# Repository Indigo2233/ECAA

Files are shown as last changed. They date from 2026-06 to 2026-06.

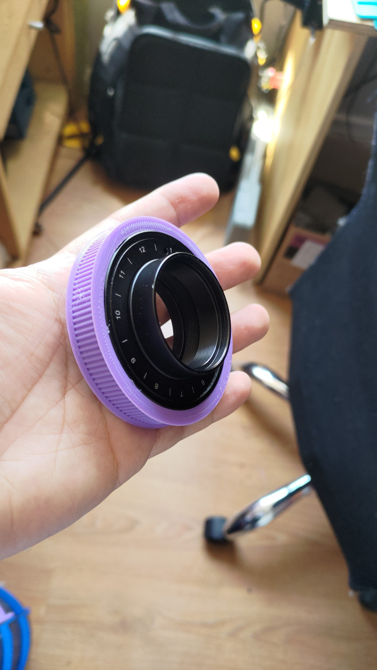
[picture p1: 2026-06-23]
m42/images/IMG-20220209-WA0020.jpeg

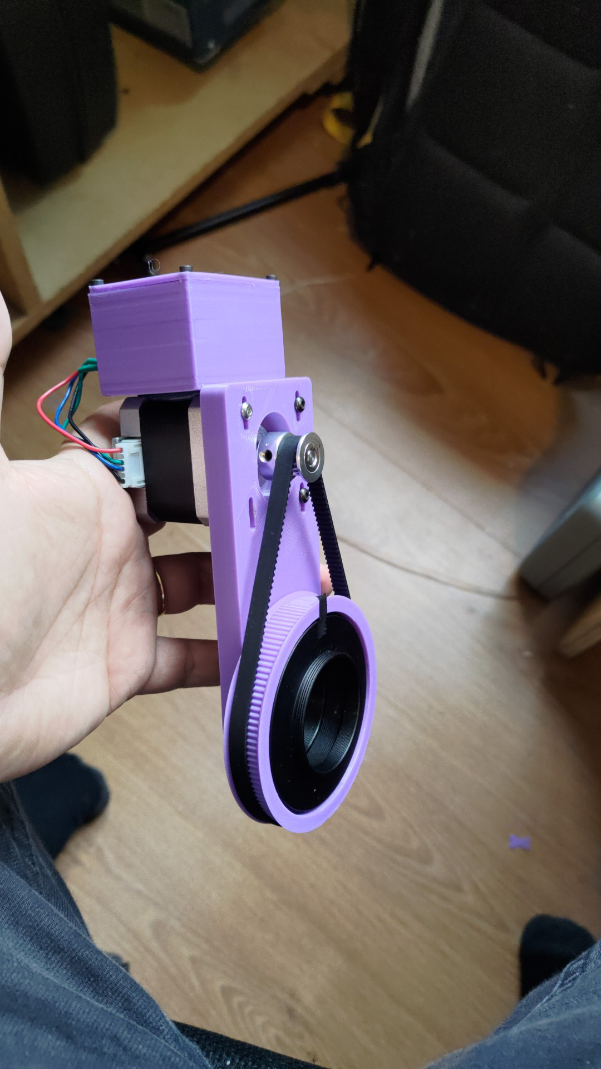
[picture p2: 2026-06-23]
m42/images/IMG-20220209-WA0058.jpeg

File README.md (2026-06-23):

# ECAA ESP8266 Rotator

ECAA is an ESP8266-based electric camera angle adjuster / field rotator project.
It includes firmware for the controller, an ASCOM rotator driver for PC
astronomy software, a simple ASCOM test client, and mechanical reference assets.

## Features

- ESP8266 firmware with AP+STA WiFi.
- Mobile control page served by the ESP8266 at `http://192.168.4.1`.
- ASCOM-compatible TCP text protocol on port `4030`.
- WebSocket status updates on port `81`.
- Legacy Arduino Nano firmware kept as a protocol reference.
- ASCOM .NET Framework driver with Serial and TCP transport options.
- Mechanical assets for M42 and M54 variants.

## Repository Layout

- `ESP8266RotatorFirmware/`
  - Main ESP8266 firmware, firmware-specific README, and a browser-only mock
    control page.
- `ArduinoRotatorFirmware_ver1008/`
  - Original Arduino Nano firmware.
- `driver/scopefocusRotatorDriver/`
  - ASCOM rotator driver source. The folder name is historical; the public
    ASCOM driver identity is `ASCOM.ECAA.Rotator`.
- `driver/RotatorTest/`
  - Simple Windows Forms ASCOM test client.
- `m42/` and `m54/`
  - STL, SolidWorks, and reference image assets.
- `AGENTS.md`
  - Detailed implementation notes for future development agents.

## Default WiFi

- AP SSID: `CAA-Rotator-<chipid>`
- AP password: `012345678`
- Mobile control page: `http://192.168.4.1`
- ASCOM TCP port: `4030`
- WebSocket port: `81`

## Hardware Summary

Default ESP8266 board target:

- Wemos D1 mini or NodeMCU

Default wiring:

- STEP: D1 / GPIO5
- DIR: D2 / GPIO4
- ENABLE: D5 / GPIO14, active low
- HALL: D6 / GPIO12, active low
- CW: D7 / GPIO13, active low
- CCW: D0 / GPIO16, active low with an external 10k pull-up to 3.3V

Soldering guide for the photographed NodeMCU-style board:

- Orient the board with the USB connector at the bottom and the ESP8266 antenna
  at the top. Use the printed pin labels on the board as the reference.
- The required signal pads are on the right-side header in the photo:
  `D0`, `D1`, `D2`, `D5`, `D6`, `D7`, `GND`, and `3V3`.
- Solder pin headers first if the rotator will be serviced later. Direct wire
  soldering is acceptable for a permanent build; add strain relief near the
  board edge.

| Board pad | Connect to | Notes |
| --- | --- | --- |
| `D1` / GPIO5 | Stepper driver `STEP`, `PUL`, or `CLK` | 3.3V logic pulse output. |
| `D2` / GPIO4 | Stepper driver `DIR` | Direction output. Reverse in firmware or web UI if rotation is inverted. |
| `D5` / GPIO14 | Stepper driver `ENABLE` or `ENA` | Active low. The firmware pulls it low when the driver should be enabled. |
| `D6` / GPIO12 | Hall sensor output | Active low. Sensor output must stay at 3.3V or lower. |
| `D7` / GPIO13 | CW manual button | Wire the other side of the button to `GND`. |
| `D0` / GPIO16 | CCW manual button | Wire the other side of the button to `GND`; add a 10k pull-up from `D0` to `3V3`. |
| `3V3` | Hall sensor VCC, or driver logic VDD when supported | Use only for low-current 3.3V logic or sensors. |
| `GND` | Stepper driver logic GND, Hall GND, button common, and 12V supply negative | Common ground is required for STEP/DIR/ENABLE to be valid. |
| USB or `Vin` | ESP8266 board power | Prefer USB during testing. If using a buck converter, feed regulated 5V to `Vin` and `GND`. |

External stepper driver wiring:

| Driver terminal | Connect to | Notes |
| --- | --- | --- |
| `VMOT`, `12V+`, or motor supply `+` | External 12V positive | Set the driver current limit before load testing. |
| Motor supply `GND` | External 12V negative and ESP8266 `GND` | This is the shared power return. |
| `A+`, `A-`, `B+`, `B-` | Stepper motor coils | Swap one coil pair if the physical direction is unsuitable. |
| `VDD` or `VIO` | `3V3` only when the driver supports 3.3V logic | Use a level shifter or compatible driver for 5V-only logic inputs. |
| Microstep pins | Fixed high/low jumpers as required | Update `stepsPerDegree` after changing microstepping. |

Power requirements:

- Use an external 12V supply for the stepper driver motor power.
- Connect ESP8266 GND, stepper driver logic GND, and the 12V supply negative
  terminal together.
- Keep 12V away from ESP8266 `5V`, `3.3V`, and GPIO pins.
- ESP8266 GPIO uses 3.3V logic. Use level shifting or a 3.3V-compatible stepper
  driver when required.

Initial electrical check:

1. Power only the ESP8266 over USB and confirm the AP appears.
2. Wire `GND`, `STEP`, `DIR`, and `ENABLE` to the stepper driver with motor
   power disconnected.
3. Verify `ENABLE` changes state and `STEP` pulses during a small move command.
4. Connect the Hall sensor and confirm `Home` reacts when the sensor is
   triggered.
5. Connect the external 12V supply and motor after the driver current limit is
   set.

Home and zero behavior:

- The Hall sensor is only the mechanical reference point.
- `Set 0` stores the current physical position as the user-defined zero angle.
- The saved zero offset is persistent.
- `Home` finds the Hall sensor first, then automatically returns to the saved
  user-defined `0 deg` position.

## Firmware Build

Expected Arduino environment:

- Arduino ESP8266 core
- Board: Wemos D1 mini or NodeMCU
- Libraries: `AccelStepper`, `WebSocketsServer`

Open and upload:

```text
ESP8266RotatorFirmware/ESP8266RotatorFirmware.ino
```

Preview the mobile control page locally:

```text
ESP8266RotatorFirmware/mock-control-page.html
```

After upload:

1. Power the ESP8266.
2. Connect a phone to `CAA-Rotator-<chipid>` using password `012345678`.
3. Open `http://192.168.4.1`.
4. Verify status updates, halt, home, and small relative moves before attaching
   motor load.

## ASCOM Driver

Public identity:

- ProgID: `ASCOM.ECAA.Rotator`
- Chooser name: `ECAA ESP8266 Rotator`
- DLL name: `ASCOM.ECAA.Rotator.dll`

Build requirements:

- Visual Studio or MSBuild
- .NET Framework 4.8 Developer Pack
- ASCOM Platform developer components

Build command from repository root:

```powershell
& "C:\Program Files\Microsoft Visual Studio\2022\Community\MSBuild\Current\Bin\MSBuild.exe" driver\scopefocusRotatorDriver\scopefocusRotatorDriver.csproj /p:Configuration=Release /p:RegisterForComInterop=false /m
```

Driver setup defaults for ESP8266 TCP:

- Transport: `TCP`
- Host: `192.168.4.1`
- Port: `4030`
- Timeout: `3000`
- Steps/degree: `100`

## Legacy Text Protocol

Commands are ASCII text terminated by `#`.

- `G#`: returns `P <steps>;M <true|false>#`
- `M <steps>#`: move to absolute step position
- `P <steps>#`: set current logical step position and update the saved zero offset
- `H#`: start homing
- `S#`: stop movement
- `R <0|1>#`: set direction inversion
- `C <0|1>#`: set continuous hold
- `V#`: firmware version
- `I#`: JSON status
- `D <stepsPerDegree>#`: set steps per degree and recompute two-turn range

## Validation Checklist

- ESP8266 AP starts with the expected SSID and password.
- `http://192.168.4.1` loads the control page from a phone.
- `GET /api/status` returns JSON.
- TCP command `G#` on port `4030` returns a `#`-terminated response.
- ASCOM setup dialog shows `Serial` and `TCP` transport options.
- ASCOM test client can connect, read position, move, halt, and home.

## Development Notes

- Build outputs, Visual Studio caches, generated installers, DLLs, PDBs, and
  Arduino build artifacts are ignored by `.gitignore`.
- Keep `AGENTS.md` updated when driver identity, protocol, wiring, or build
  assumptions change.

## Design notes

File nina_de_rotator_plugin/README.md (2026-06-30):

# Alt-Az De-Rotator Plugin for N.I.N.A.

Actively compensates for field rotation on Alt-Azimuth telescope mounts by
calculating the required rotation rate and commanding an ASCOM Rotator (e.g. ECAA).

Forked from [ArchitectJuan/Nina_Rotator_Plugin](https://github.com/ArchitectJuan/Nina_Rotator_Plugin)
with fixes for the ECAA/ASCOM ecosystem:

- **Accumulated error tracking**: slow field rotation rates (< 36°/hr) are
  accumulated across polling cycles and applied in one move when the deadband
  (0.01°) is reached, preventing stalls.
- **Direct MoveAbsolute**: bypasses the NINA mediator's `Move()` method which
  does not reliably call the ASCOM driver in NINA 3.x.
- **Diagnostic logging**: logs each derotation move with the applied angle
  and current field-rotation rate.

## Build

Requires .NET 8.0 SDK + local NINA installation.

```powershell
dotnet build AltAzDeRotator.csproj -c Release
```

## Install

1. Copy contents of `Builds\AltAz.DeRotator\` into
   `%localappdata%\NINA\Plugins\3.0.0\AltAz.DeRotator\`
2. Restart NINA.
3. Connect both Telescope (Alt-Az) and Rotator (e.g. ECAA) in Equipment tab.
4. Open **Alt-Az De-Rotator** dockable window, toggle **Enable De-Rotation** ON.

## License

MIT
- **Micro-step Prevention:** Intelligent 0.01-degree thresholding ensures your Rotator is only commanded when necessary, preventing unnecessary hardware wear.
- **N.I.N.A. 3.x Compatibility:** Built against the modern .NET 8.0 framework and N.I.N.A. 3.0 Managed Extensibility Framework (MEF).

## Version History
- **V1.1.0:** Added User Interface and On/Off switch control. Migrated to DockableVM pattern.
- **V1.0.0:** Initial Release. Features background polling service, dynamic rate calculation, and MEF dependency injection.

## Installation
Refer to the `UserGuide.md` for complete installation and usage instructions.

## Building from Source
This project requires Visual Studio or the .NET 8.0 SDK.
Run `dotnet build AltAzDeRotator.csproj` to compile the library. Output files are automatically copied to the `Builds\Nina_Rotator_Plugin_V1.0` folder.





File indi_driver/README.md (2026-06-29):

# INDI Driver for CAA Rotator

INDI driver for the CAA (Camera Angle Adjuster) — supports ESP8266 and Arduino
Nano hardware, over TCP or Serial.

Firmware repo: <https://github.com/Indigo2233/ECAA>

## Hardware Support

| Hardware | Transport | Default |
|---|---|---|
| ESP8266 | TCP (WiFi) | `192.168.4.1:4030` |
| ESP8266 | Serial (USB) | `/dev/ttyUSB0` @ 9600 |
| Arduino Nano | Serial (USB) | `/dev/ttyUSB0` @ 9600 |

All three use the same text protocol — switch transport in the INDI control
panel, no need to restart the driver.

## Build & Install

```bash
mkdir build && cd build
cmake .. -DCMAKE_INSTALL_PREFIX=/usr
make -j$(nproc)
sudo make install
```

## Run

```bash
# Standalone (waits for INDI client):
indi_caa_rotator

# With debug output:
INDI_DEBUG=1 indi_caa_rotator
```

In Ekos / KStars: Profile Editor → Rotator → **CAA Rotator**.

## INDI Properties

| Group | Property | Description |
|---|---|---|
| Transport | `TRANSPORT` | Switch between TCP / Serial |
| TCP Config | `TCP_HOST`, `TCP_PORT` | ESP8266 WiFi address |
| Serial Config | `SERIAL_PORT`, `SERIAL_BAUD` | Serial port and baud rate |
| Settings | `STEPS_PER_DEGREE` | Motor steps per degree (e.g. 635) |
| Settings | `CMD_TIMEOUT` | Command timeout in ms |
| Main | `GOTO` | Move to absolute sky angle |
| Main | `SYNC` | Align current position to sky angle |
| Main | `HOME` | Seek Hall sensor and return to zero |
| Main | `ABORT` | Halt movement |
| Info | `FW_VERSION` | Firmware version (read-only) |

## Protocol

Text commands terminated with `#`:

| Cmd | Description |
|-----|---|
| `G#` | Status: `P <steps>;M <moving>#` |
| `M <n>#` | Move to logical step position |
| `P <n>#` | Set current logical position (sync) |
| `H#` | Start homing |
| `S#` | Stop |
| `V#` | Firmware version |
| `D <n>#` | Set steps per degree (firmware int only) |

## Notes

- The driver sends `D <int>#` on connect to sync firmware steps-per-degree.
  The value is truncated to integer for firmware compatibility; full double
  precision is used for driver-side angle conversion.
- Serial transport uses POSIX termios (Linux/macOS) or Win32 CreateFile (Windows).
  Both serial and TCP work on all platforms.
- Homing is asynchronous; the driver polls `G#` until firmware reports idle.

## License

LGPL-2.1+ (same as libindi)

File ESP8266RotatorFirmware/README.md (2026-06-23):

# ESP8266RotatorFirmware

Arduino sketch for the ESP8266 CAA rotator controller.

`mock-control-page.html` is a browser-only preview of the control page. It uses
mock state and does not require an ESP8266.

## Board and libraries

- Board: Wemos D1 mini or NodeMCU
- Arduino ESP8266 core
- Libraries: `AccelStepper`, `WebSocketsServer`

## Default network

- AP SSID: `CAA-Rotator-<chipid>`
- AP password: `012345678`
- Control page: `http://192.168.4.1`
- ASCOM TCP protocol port: `4030`
- WebSocket status port: `81`

## Default wiring

- STEP: D1 / GPIO5
- DIR: D2 / GPIO4
- ENABLE: D5 / GPIO14, active low
- HALL: D6 / GPIO12, active low
- CW: D7 / GPIO13, active low
- CCW: D0 / GPIO16, active low with an external 10k pull-up to 3.3V

## Soldering guide

For the NodeMCU-style board shown in the project discussion, orient the board
with USB at the bottom and the ESP8266 antenna at the top. Follow the silkscreen
pin labels on the board.

| Board pad | Connect to | Notes |
| --- | --- | --- |
| `D1` / GPIO5 | Stepper driver `STEP`, `PUL`, or `CLK` | 3.3V logic pulse output. |
| `D2` / GPIO4 | Stepper driver `DIR` | Direction output. Toggle Reverse in the web UI if needed. |
| `D5` / GPIO14 | Stepper driver `ENABLE` or `ENA` | Active low. |
| `D6` / GPIO12 | Hall sensor output | Active low. Keep the output at 3.3V or lower. |
| `D7` / GPIO13 | CW manual button | Button shorts to `GND` when pressed. |
| `D0` / GPIO16 | CCW manual button | Button shorts to `GND`; add 10k from `D0` to `3V3`. |
| `3V3` | Hall VCC, or driver logic VDD when supported | Low-current 3.3V logic only. |
| `GND` | Driver logic GND, Hall GND, button common, and 12V negative | All logic signals require common ground. |
| USB or `Vin` | ESP8266 power | Use USB for testing, or regulated 5V to `Vin` and `GND`. |

External driver power:

- 12V positive goes to the stepper driver motor supply positive terminal.
- 12V negative goes to the stepper driver motor supply GND and ESP8266 `GND`.
- Stepper motor coils connect only to the driver motor outputs.
- Driver logic `VDD` / `VIO` may use ESP8266 `3V3` only when that driver accepts
  3.3V logic.
- Set the driver current limit before connecting the motor load.

Use an external 12V supply for the stepper driver motor power. Connect ESP8266
GND, stepper driver logic GND, and the 12V supply negative terminal together.
The ESP8266 GPIO pins are 3.3V logic. Do not connect 12V to the ESP8266 5V,
3.3V, or GPIO pins.

## Home and zero position

- The Hall sensor is used only as the mechanical reference point.
- `Set 0` stores the current physical position as the user-defined zero angle.
- The user-defined zero angle is saved in EEPROM as a step offset from the Hall
  reference.
- `Home` first finds the Hall sensor, resets the mechanical reference, then
  automatically moves to the saved user-defined `0 deg` position.

## Legacy protocol

Commands are ASCII text terminated by `#`.

- `G#`: returns `P <steps>;M <true|false>#`
- `M <steps>#`: move to an absolute step position
- `P <steps>#`: set the current logical step position and update the saved zero offset
- `H#`: start homing
- `S#`: stop movement
- `R <0|1>#`: set direction inversion
- `C <0|1>#`: set continuous hold
- `V#`: firmware version
- `I#`: JSON status
- `D <stepsPerDegree>#`: set steps per degree and recompute the two-turn range

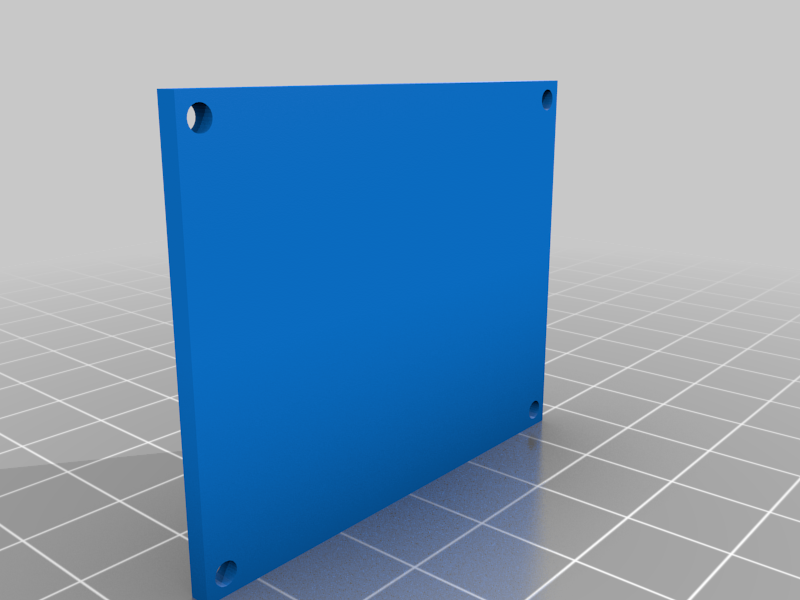
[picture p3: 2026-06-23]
m42/images/tapa_caja_rotador.png

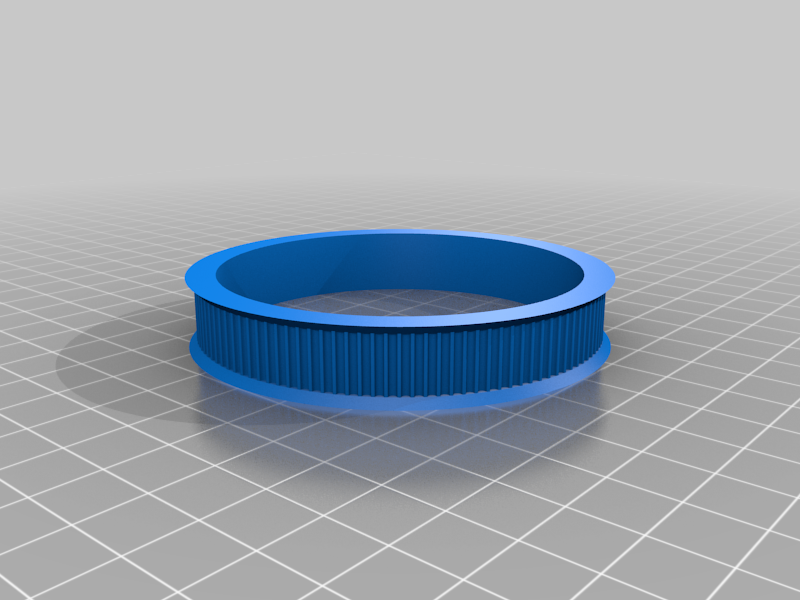
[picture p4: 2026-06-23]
m42/images/pulley_rotator.png

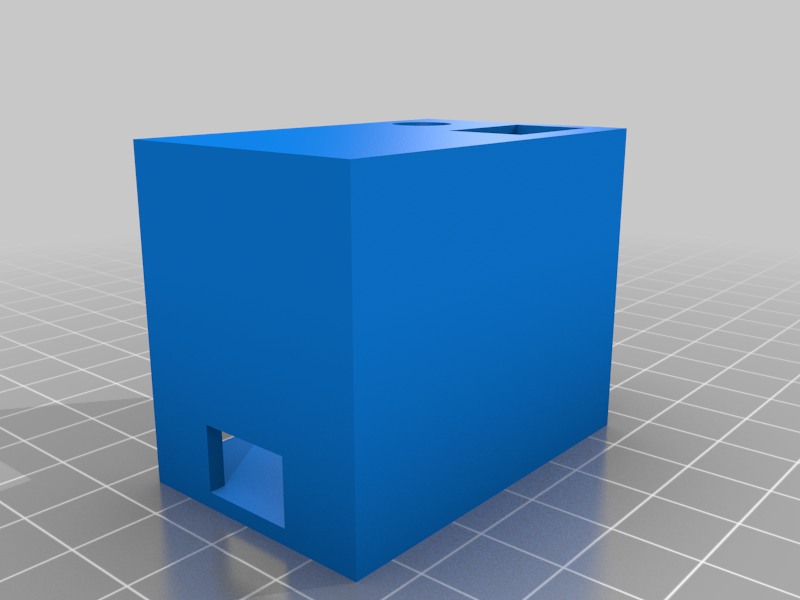
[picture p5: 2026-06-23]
m42/images/caja_rotador.png

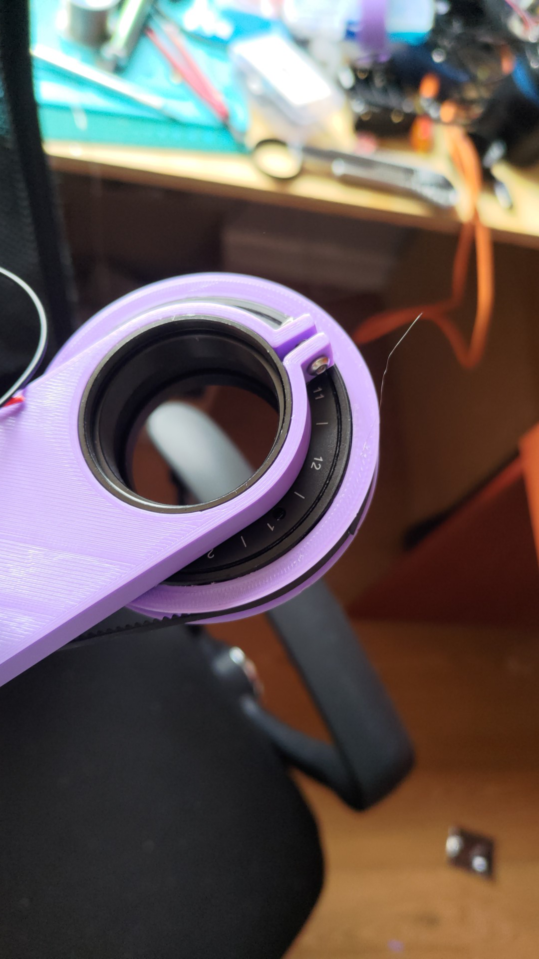
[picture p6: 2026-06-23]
m42/images/IMG-20220209-WA0037.jpeg

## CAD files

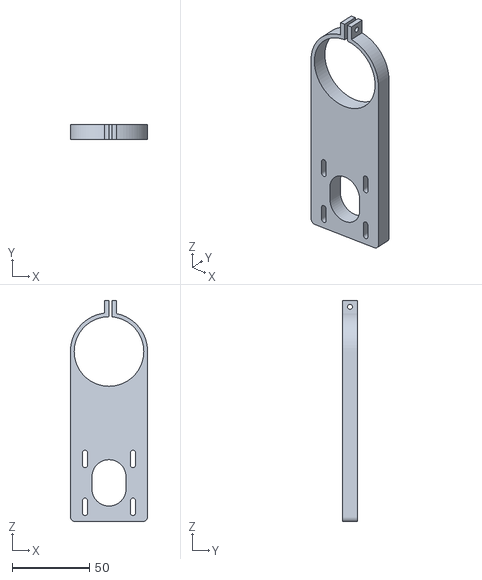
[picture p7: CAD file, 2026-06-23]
m42/rotador_astroquinta_v1.stl
50.0 x 10.0 x 143.0

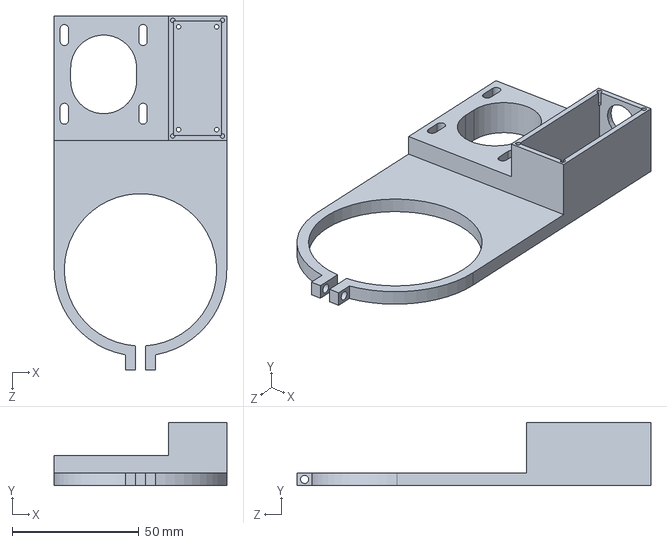
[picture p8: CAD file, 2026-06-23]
m54/m54_v2.1_B.SLDPRT
68.0 x 25.0 x 139.5 mm

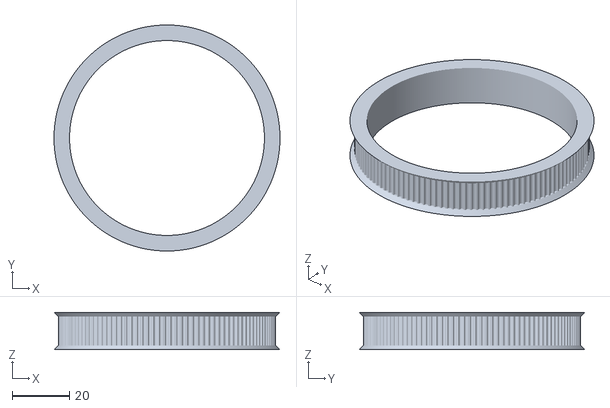
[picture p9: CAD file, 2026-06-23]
m42/pulley_rotator.stl
78.9 x 78.9 x 13.0

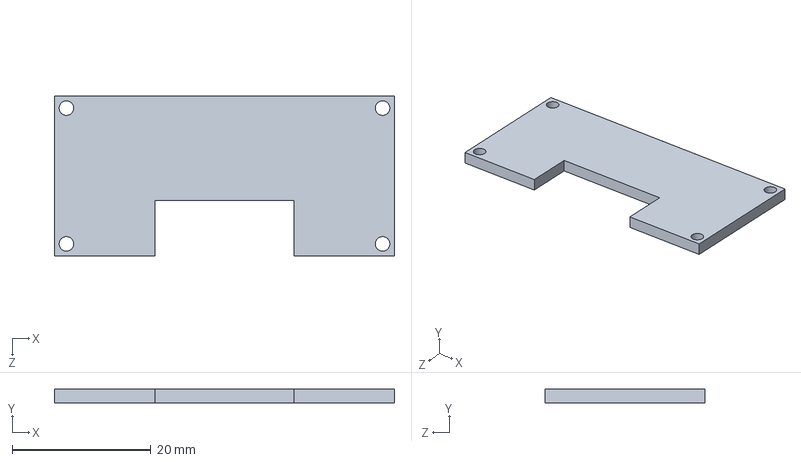
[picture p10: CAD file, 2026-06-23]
m54/m54 cover.SLDPRT
49.0 x 2.00 x 23.0 mm

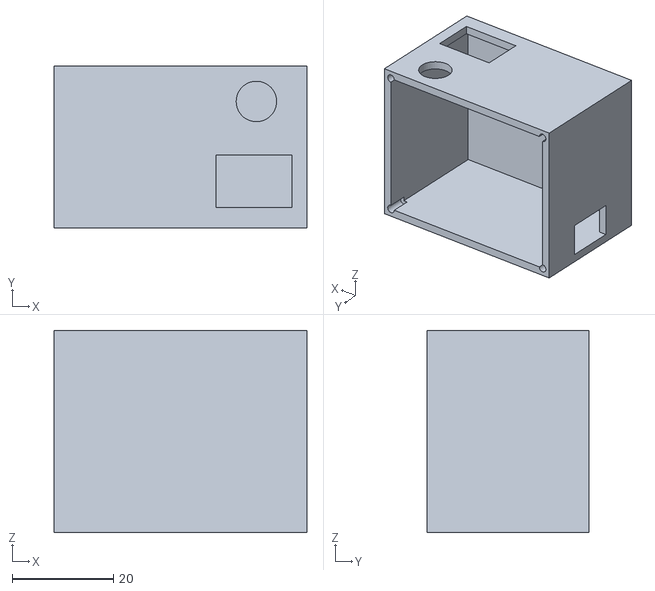
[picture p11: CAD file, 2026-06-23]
m42/caja_rotador.stl
50.0 x 32.0 x 40.0

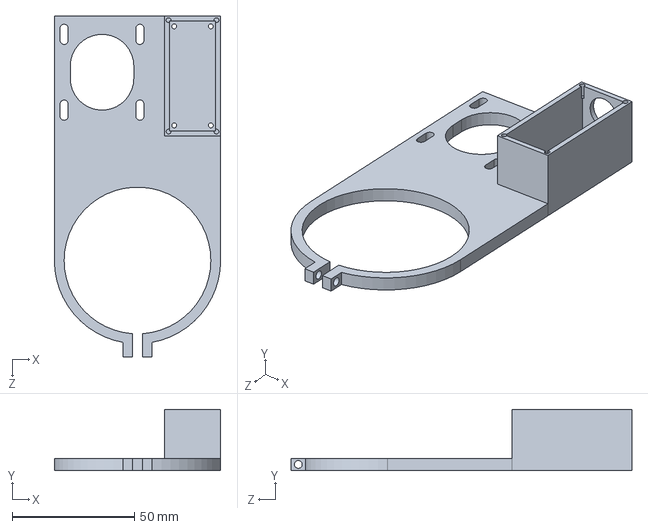
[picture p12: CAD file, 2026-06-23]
m54/m54_v2.SLDPRT
68.0 x 25.0 x 139.5 mm

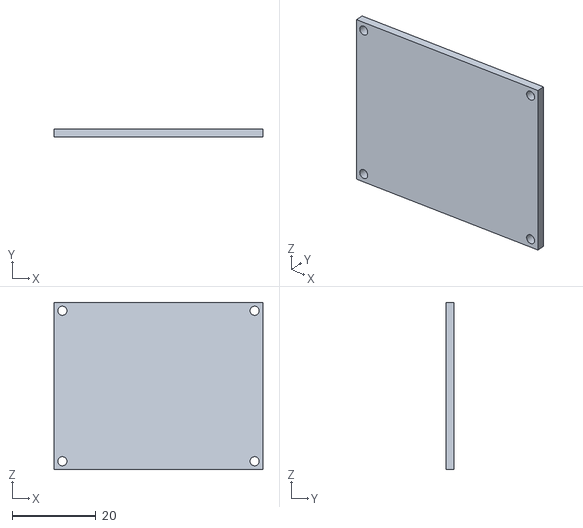
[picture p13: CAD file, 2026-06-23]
m42/tapa_caja_rotador.stl
50.0 x 2.00 x 40.0

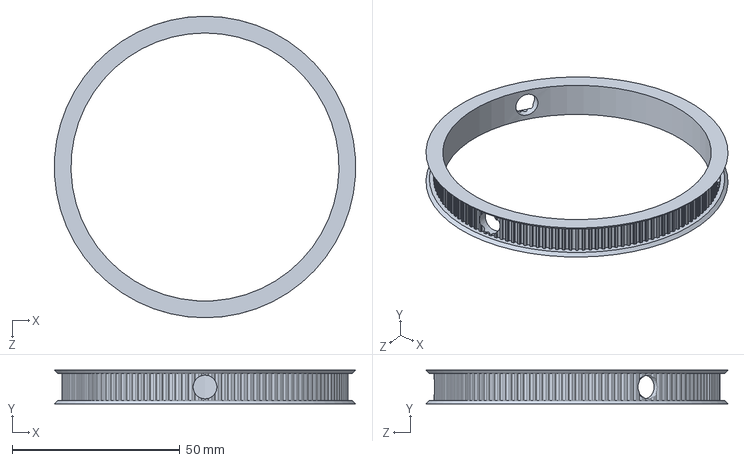
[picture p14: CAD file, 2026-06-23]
m54/m54 gear.SLDPRT
89.8 x 10.0 x 90.0 mm

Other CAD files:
m54/m54 cover.STL
m54/m54 gear.STL
m54/m54_v2.1_B.STL
m54/m54_v2.STL

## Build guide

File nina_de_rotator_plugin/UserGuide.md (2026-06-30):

# Alt-Az De-Rotator User Guide

Welcome to the Alt-Az De-Rotator Plugin for N.I.N.A. This guide will walk you through the installation and operational steps to get your field rotator compensating for Alt-Azimuth tracking.

## 1. Installation

1. Navigate to the `Builds\AltAz.DeRotator` directory in this repository.
2. Ensure you have the following files:
   - `AltAzDeRotator.dll`
   - `manifest.json`
3. Locate your N.I.N.A. 3.0 Plugins version folder. By default, this is located at:
   `%localappdata%\NINA\Plugins\3.0.0`
4. Create a new folder inside the `3.0.0` directory named exactly **`AltAz.DeRotator`**.
5. Copy the contents of `Builds\AltAz.DeRotator` into this new folder.
6. **Important**: The folder name must match the plugin ID `AltAz.DeRotator`.
7. Restart N.I.N.A.

## 2. Requirements

- N.I.N.A. version 3.0 or higher.
- A connected and communicating Telescope mount (ASCOM, EQMOD, GreenSwamp, etc.) with valid Altitude and Azimuth telemetry.
- A connected Rotator (ASCOM-compatible) capable of Absolute Positioning movements.

## 3. Operation

Once initialized, the plugin provides a dedicated UI for monitoring and control.

1. **Open the Status Window:** In N.I.N.A., go to the **Plugins** tab or check the **Windows** menu for "Alt-Az De-Rotator". This dockable window shows real-time Altitude, Azimuth, and calculated Rotation Rate.
2. **Connect your Equipment:** Ensure both your Telescope and your Rotator are connected in the **Equipment** tab.
3. **Enable/Disable:** Use the **Enable De-Rotation** checkbox in the plugin window to start or stop active compensation. 
4. **Automatic Adjustments:** Every second, if enabled, the plugin calculates the required position offset. If the required change exceeds `0.01 degrees`, a command is issued to the Rotator. 

*Note: You can dock the status window anywhere in your N.I.N.A. layout to keep an eye on rotation during your session!*

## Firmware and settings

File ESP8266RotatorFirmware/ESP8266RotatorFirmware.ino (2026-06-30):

#include <AccelStepper.h>
#include <EEPROM.h>
#include <ESP8266WebServer.h>
#include <ESP8266WiFi.h>
#include <ESP8266mDNS.h>
#include <WebSocketsServer.h>
#include <ctype.h>
#include <math.h>

#define STEP_PIN D1
#define DIR_PIN D2
#define ENABLE_PIN D5
#define HALL_PIN D6
#define CW_PIN D7
#define CCW_PIN D3

#define DEVICE_RESPONSE "CAA ESP8266 Rotator ver 2001"
#define FIRMWARE_VERSION 2001
#define EEPROM_SIZE 512
#define SETTINGS_MAGIC 0xCAAF8266UL
#define ASCOM_TCP_PORT 4030
#define WEBSOCKET_PORT 81
#define MAX_TCP_CLIENTS 4

const char *AP_PASSWORD = "012345678";
IPAddress apIp(192, 168, 4, 1);
IPAddress apGateway(192, 168, 4, 1);
IPAddress apSubnet(255, 255, 255, 0);

struct RotatorSettings {
  uint32_t magic;
  long position;
  int stepsPerDegree;
  long maxSteps;
  int maxSpeed;
  int acceleration;
  int manualMoveStepSize;
  int findHomeStepSize;
  bool hold;
  bool reversed;
  char staSsid[32];
  char staPassword[64];
  long homeOffsetSteps;
  char tcpPassword[16];
  char apPassword[32];
  char nickname[32];
  int backlashSteps;
};

RotatorSettings settings;
AccelStepper stepper(AccelStepper::DRIVER, STEP_PIN, DIR_PIN);
ESP8266WebServer server(80);
WebSocketsServer webSocket(WEBSOCKET_PORT);
WiFiServer tcpServer(ASCOM_TCP_PORT);
WiFiClient tcpClients[MAX_TCP_CLIENTS];

String tcpBuffers[MAX_TCP_CLIENTS];
bool tcpAuthenticated[MAX_TCP_CLIENTS];
String serialBuffer;
String apSsid;
String mdnsHostname;

bool positionSaved = true;
bool findingHome = false;
bool homeFound = false;
bool backlashCompensating = false;
long backlashFinalTarget = 0;
bool manualMoveCW = false;
bool manualMoveCCW = false;
int lastCWState = HIGH;
int lastCCWState = HIGH;
unsigned long lastCWDebounce = 0;
unsigned long lastCCWDebounce = 0;
unsigned long lastStatusBroadcast = 0;
const unsigned long debounceDelayMs = 20;

const char INDEX_HTML[] PROGMEM = R"rawliteral(
<!doctype html>
<html lang="en">
<head>
<meta charset="utf-8">
<meta name="viewport" content="width=device-width,initial-scale=1,viewport-fit=cover">
<title>CAA Rotator</title>
<style>
:root{color-scheme:dark;--bg:#111318;--panel:#1a1f28;--panel2:#202734;--line:#384252;--text:#f2f5f8;--muted:#aeb8c6;--accent:#4db6ac;--warn:#f4b24e;--danger:#ee6b63;--ok:#7bc96f}
*{box-sizing:border-box}
body{margin:0;background:var(--bg);color:var(--text);font-family:system-ui,-apple-system,Segoe UI,Roboto,Arial,sans-serif;letter-spacing:0}
main{max-width:720px;margin:0 auto;padding:18px 14px 28px}
header{display:flex;align-items:center;justify-content:space-between;gap:12px;margin-bottom:14px}
h1{font-size:22px;margin:0;font-weight:680}
.status{font-size:13px;color:var(--muted)}
.grid{display:grid;grid-template-columns:1fr;gap:10px}
section{border:1px solid var(--line);background:var(--panel);border-radius:8px;padding:12px}
.readout{display:grid;grid-template-columns:1fr 1fr;gap:10px}
.metric{background:var(--panel2);border:1px solid var(--line);border-radius:8px;padding:10px;min-height:76px}
.metric span{display:block;color:var(--muted);font-size:12px;margin-bottom:8px}
.metric strong{font-size:22px;line-height:1.2;white-space:nowrap}
.row{display:flex;gap:8px;align-items:center;flex-wrap:wrap}
.controls{display:grid;grid-template-columns:repeat(3,1fr);gap:8px}
button,input,select{font:inherit}
button{border:1px solid var(--line);background:#263244;color:var(--text);border-radius:8px;min-height:44px;padding:0 12px;cursor:pointer}
button:active{transform:translateY(1px)}
button.primary{background:var(--accent);border-color:var(--accent);color:#071211;font-weight:700}
button.warn{background:var(--warn);border-color:var(--warn);color:#211400;font-weight:700}
button.danger{background:var(--danger);border-color:var(--danger);color:#210706;font-weight:700}
button.toggle.active{background:var(--ok);border-color:var(--ok);color:#061008;font-weight:700}
label{display:grid;gap:5px;color:var(--muted);font-size:12px;min-width:0}
input{width:100%;background:#121720;color:var(--text);border:1px solid var(--line);border-radius:8px;min-height:42px;padding:8px 10px}
.form{display:grid;grid-template-columns:1fr 1fr;gap:10px}
.wide{grid-column:1/-1}
.dial{aspect-ratio:1;max-width:330px;margin:6px auto 12px;border:2px solid var(--line);border-radius:50%;position:relative;background:radial-gradient(circle,#202734 0,#151a22 68%,#111318 100%)}
.needle{position:absolute;left:50%;top:50%;width:3px;height:43%;background:var(--accent);transform-origin:50% 0;transform:rotate(0deg);border-radius:3px}
.hub{position:absolute;left:50%;top:50%;width:18px;height:18px;background:var(--accent);border-radius:50%;transform:translate(-50%,-50%)}
.tick{position:absolute;color:var(--muted);font-size:12px}
.t0{left:50%;top:8px;transform:translateX(-50%)}.t90{right:8px;top:50%;transform:translateY(-50%)}.t180{left:50%;bottom:8px;transform:translateX(-50%)}.t270{left:8px;top:50%;transform:translateY(-50%)}
.small{font-size:12px;color:var(--muted)}
.toast{font-size:13px;color:var(--ok);min-height:20px;transition:color .3s;display:flex;align-items:center;gap:6px}
.toast.info{color:var(--accent)}
.toast.warn{color:var(--warn)}
.spinner{display:inline-block;width:14px;height:14px;border:2px solid var(--line);border-top-color:var(--accent);border-radius:50%;animation:spin .7s linear infinite;flex-shrink:0}
@keyframes spin{to{transform:rotate(360deg)}}
@media (min-width:680px){.grid{grid-template-columns:1fr 1fr}.span{grid-column:1/-1}}
</style>
</head>
<body>
<main>
<header>
<h1 id="pageTitle">CAA Rotator</h1>
<div class="status" id="link">Connecting</div>
</header>
<div class="grid">
<section class="span">
<div class="dial" id="dial">
<div class="tick t0">0</div><div class="tick t90">90</div><div class="tick t180">180</div><div class="tick t270">270</div>
<div class="needle" id="needle"></div><div class="hub"></div>
</div>
<div class="readout">
<div class="metric"><span>Angle</span><strong id="angle">--</strong></div>
<div class="metric"><span>Steps</span><strong id="steps">--</strong></div>
</div>
</section>
<section>
<div class="form">
<label class="wide">Absolute angle<input id="absoluteAngle" type="number" min="0" max="359.99" step="0.01" value="0"></label>
<button class="primary wide" id="moveAbsolute">Move</button>
<button data-rel="-10">-10</button><button data-rel="-1">-1</button><button data-rel="-0.1">-0.1</button>
<button data-rel="0.1">+0.1</button><button data-rel="1">+1</button><button data-rel="10">+10</button>
<button class="danger" id="halt">STOP</button><button id="home">Home</button><button id="setZero">Set 0</button>
</div>
</section>
<section>
<div class="form">
<button class="toggle" id="hold">Hold</button>
<button class="toggle" id="reverse">Reverse</button>
<label>Steps/degree<input id="stepsPerDegree" type="number" min="1" step="1"></label>
<label>Max speed<input id="maxSpeed" type="number" min="1" step="1"></label>
<label>Acceleration<input id="acceleration" type="number" min="1" step="1"></label>
<label>Manual step<input id="manualStep" type="number" min="1" step="1"></label>
<label>Device Name<input id="nickname" type="text" maxlength="31" placeholder="mDNS hostname"></label>
<label>AP Password<input id="apPassword" type="password" maxlength="31" placeholder="default: 012345678"></label>
<label>STA SSID<input id="staSsid" type="text" maxlength="31"></label>
<label>STA Password<input id="staPassword" type="password" maxlength="63"></label>
<label>TCP Password<input id="tcpPassword" type="password" maxlength="15" placeholder="empty = no auth"></label>
<button class="primary wide" id="saveSettings">Save settings</button>
<div class="toast wide" id="saveMsg"></div>
<div class="small wide" id="network"></div>
</div>
</section>
</div>
</main>
<script>
const $=id=>document.getElementById(id);
let state={};
async function api(path,body){
 const opt=body===undefined?{}:{method:'POST',headers:{'Content-Type':'application/json'},body:JSON.stringify(body)};
 const res=await fetch(path,opt);
 if(!res.ok)throw new Error(path);
 return res.json();
}
function setState(s){
 state=s;
 const title=s.nickname?s.nickname:'CAA Rotator';
 document.title=title;
 $('pageTitle').textContent=title;
 $('angle').textContent=(s.angle??0).toFixed(2)+'°';
 $('steps').textContent=String(s.positionSteps??0);
 $('needle').style.transform='rotate('+((s.angle??0)+180)+'deg)';
 $('link').textContent=s.isMoving?'Moving':'Ready';
 $('hold').classList.toggle('active',!!s.hold);
 $('reverse').classList.toggle('active',!!s.reversed);
 $('stepsPerDegree').value=s.stepsPerDegree??100;
 $('maxSpeed').max=(s.stepsPerDegree??100)*10;
 $('maxSpeed').value=s.maxSpeed??800;
 $('acceleration').value=s.acceleration??1000;
 $('manualStep').value=s.manualStep??50;
 if(document.activeElement!==$('nickname'))$('nickname').value=s.nickname||'';
 if(document.activeElement!==$('staSsid'))$('staSsid').value=s.staSsid||'';
 if(document.activeElement!==$('tcpPassword'))$('tcpPassword').placeholder=s.tcpLocked?'••••••••':'empty = no auth';
 if(document.activeElement!==$('apPassword'))$('apPassword').placeholder=s.apCustom?'••••••••':'default: 012345678';
 const staIp=s.staIp&&s.staIp!=='0.0.0.0'?s.staIp:'not connected';
 const mdnsHost=(s.mdns||'').replace('.local','');
 $('network').innerHTML='AP: '+(s.apIp||'192.168.4.1')+' | STA: '+staIp+'<br>mDNS: <b>'+(s.mdns||'')+'</b> | TCP: '+(s.tcpPort||4030)+'<br>ASCOM Host: <b>'+mdnsHost+'</b> or <b>'+staIp+'</b>';
}
async function refresh(){try{setState(await api('/api/status'));}catch(e){$('link').textContent='Disconnected';}}
function connectWs(){
 const ws=new WebSocket('ws://'+location.hostname+':81/');
 ws.onopen=()=>{$('link').textContent='Connected'};
 ws.onmessage=e=>{try{setState(JSON.parse(e.data));}catch(_){}};
 ws.onclose=()=>{setTimeout(connectWs,1200);};
}
$('moveAbsolute').onclick=()=>api('/api/move',{angle:Number($('absoluteAngle').value)}).then(setState);
document.querySelectorAll('[data-rel]').forEach(b=>b.onclick=()=>api('/api/move',{relativeDeg:Number(b.dataset.rel)}).then(setState));
$('halt').onclick=()=>api('/api/halt',{}).then(setState);
$('home').onclick=()=>api('/api/home',{}).then(setState);
$('setZero').onclick=()=>api('/api/set-position',{angle:0}).then(setState);
$('hold').onclick=()=>api('/api/settings',{hold:!state.hold}).then(setState);
$('reverse').onclick=()=>api('/api/settings',{reversed:!state.reversed}).then(setState);
let staWaiting=false,staWatchTimer=null,staWatchCount=0;
function showMsg(text,cls,spin){
 const m=$('saveMsg');
 m.innerHTML=(spin?'<span class="spinner"></span>':'')+text;
 m.className='toast wide'+(cls?' '+cls:'');
}
async function watchStaIp(){
 if(!staWaiting)return;
 staWatchCount++;
 try{
  const s=await api('/api/status');
  if(s.staIp&&s.staIp!=='0.0.0.0'){
   staWaiting=false;
   showMsg('WiFi connected: '+s.staIp);
   if(staWatchTimer){clearInterval(staWatchTimer);staWatchTimer=null;}
   setState(s);
   return;
  }
  if(staWatchCount>30){staWaiting=false;showMsg('WiFi timeout - check SSID/password','warn');if(staWatchTimer){clearInterval(staWatchTimer);staWatchTimer=null;}}
 }catch(e){}
}
$('saveSettings').onclick=async()=>{
 const btn=$('saveSettings');
 btn.disabled=true;btn.textContent='Saving...';
 showMsg('Saving settings...','info',true);
 const body={
  stepsPerDegree:Number($('stepsPerDegree').value),
  maxSpeed:Number($('maxSpeed').value),
  acceleration:Number($('acceleration').value),
  manualStep:Number($('manualStep').value),
  nickname:$('nickname').value.trim()
 };
 const hasSta=$('staSsid').value.trim();
 if(hasSta)body.staSsid=hasSta;
 if($('staPassword').value)body.staPassword=$('staPassword').value;
 body.tcpPassword=$('tcpPassword').value;
 if($('apPassword').value)body.apPassword=$('apPassword').value;
 try{
  const s=await api('/api/settings',body);
  setState(s);
  btn.textContent='Save settings';
  btn.disabled=false;
  if(hasSta&&(!s.staIp||s.staIp==='0.0.0.0')){
   staWaiting=true;staWatchCount=0;
   showMsg('Connecting to WiFi...','info',true);
   if(staWatchTimer)clearInterval(staWatchTimer);
   staWatchTimer=setInterval(watchStaIp,1500);
  }else if(hasSta&&s.staIp&&s.staIp!=='0.0.0.0'){
   showMsg('Settings saved. WiFi: '+s.staIp);
  }else{
   showMsg('Settings saved');
  }
 }catch(e){
  btn.textContent='Save settings';
  btn.disabled=false;
  showMsg('Save failed - retry','warn');
 }
};
connectWs();
refresh();
setInterval(refresh,5000);
</script>
</body>
</html>
)rawliteral";

void saveSettings() {
  settings.magic = SETTINGS_MAGIC;
  settings.position = stepper.currentPosition();
  EEPROM.put(0, settings);
  EEPROM.commit();
}

void loadSettings() {
  EEPROM.begin(EEPROM_SIZE);
  EEPROM.get(0, settings);
  if (settings.magic != SETTINGS_MAGIC || settings.stepsPerDegree <= 0) {
    memset(&settings, 0, sizeof(settings));
    settings.magic = SETTINGS_MAGIC;
    settings.position = 20000;
    settings.stepsPerDegree = 100;
    settings.maxSteps = 40000;
    settings.maxSpeed = 800;
    settings.acceleration = 1000;
    settings.manualMoveStepSize = 50;
    settings.findHomeStepSize = 100;
    settings.hold = false;
    settings.reversed = false;
    settings.homeOffsetSteps = 0;
    strcpy(settings.apPassword, "012345678");
    EEPROM.put(0, settings);
    EEPROM.commit();
  }
  if (settings.apPassword[0] == '\0' || !isprint(settings.apPassword[0])) {
    strcpy(settings.apPassword, "012345678");
  }
  // Clean garbage tcpPassword from old EEPROM layout
  if (settings.tcpPassword[0] != '\0' && !isprint(settings.tcpPassword[0])) {
    memset(settings.tcpPassword, 0, sizeof(settings.tcpPassword));
  }
  // Clean garbage nickname from old EEPROM layout
  if (settings.nickname[0] != '\0' && !isprint(settings.nickname[0])) {
    memset(settings.nickname, 0, sizeof(settings.nickname));
  }
  if (settings.maxSteps <= 0) {
    settings.maxSteps = (long)settings.stepsPerDegree * 400L;
  }
  long center = settings.maxSteps / 2L;
  if (settings.homeOffsetSteps < -center || settings.homeOffsetSteps > center) {
    settings.homeOffsetSteps = 0;
  }
  // Default backlash compensation: 5 degrees
  if (settings.backlashSteps <= 0 || settings.backlashSteps > settings.stepsPerDegree * 30) {
    settings.backlashSteps = settings.stepsPerDegree * 5;
  }
}

void applyMotionSettings() {
  stepper.setMaxSpeed(settings.maxSpeed);
  stepper.setAcceleration(settings.acceleration);
  stepper.setPinsInverted(settings.reversed, false, false);
}

void updateEnablePin() {
  if (stepper.distanceToGo() != 0 || settings.hold) {
    digitalWrite(ENABLE_PIN, LOW);
  } else {
    digitalWrite(ENABLE_PIN, HIGH);
  }
}

bool hallTriggered() {
  return digitalRead(HALL_PIN) == LOW;
}

long mechanicalHomeSteps() {
  return settings.maxSteps / 2L;
}

long zeroPhysicalSteps() {
  return mechanicalHomeSteps() + settings.homeOffsetSteps;
}

long physicalToLogicalSteps(long physicalSteps) {
  return physicalSteps - settings.homeOffsetSteps;
}

long logicalToPhysicalSteps(long logicalSteps) {
  return logicalSteps + settings.homeOffsetSteps;
}

void clampHomeOffset() {
  // Limit homeOffsetSteps to ±half of physical range
  // Physical range (0 to maxSteps) ensures no excessive rotation
  long maxOffset = settings.maxSteps / 2L;
  if (settings.homeOffsetSteps < -maxOffset) {
    settings.homeOffsetSteps = -maxOffset;
  }
  if (settings.homeOffsetSteps > maxOffset) {
    settings.homeOffsetSteps = maxOffset;
  }
}

void setCurrentLogicalPosition(long logicalSteps) {
  settings.homeOffsetSteps = stepper.currentPosition() - logicalSteps;
  clampHomeOffset();
}

float stepsToAngle(long physicalSteps) {
  long logicalSteps = physicalToLogicalSteps(physicalSteps);
  float angle = ((float)logicalSteps - mechanicalHomeSteps()) / settings.stepsPerDegree;
  while (angle < 0.0F) angle += 360.0F;
  while (angle >= 360.0F) angle -= 360.0F;
  return angle;
}

float normalizeAngle(float angle) {
  while (angle < 0.0F) angle += 360.0F;
  while (angle >= 360.0F) angle -= 360.0F;
  return angle;
}

bool physicalStepIsInRange(long physicalSteps) {
  return physicalSteps >= 0 && physicalSteps <= settings.maxSteps;
}

long choosePhysicalTarget(long physicalA, long physicalB) {
  bool validA = physicalStepIsInRange(physicalA);
  bool validB = physicalStepIsInRange(physicalB);
  if (validA && validB) {
    long current = stepper.currentPosition();
    return abs(current - physicalA) <= abs(current - physicalB) ? physicalA : physicalB;
  }
  if (validA) {
    return physicalA;
  }
  return physicalB;
}

long angleToPhysicalSteps(float angle) {
  float normalized = normalizeAngle(angle);
  long logicalA = lround(normalized * settings.stepsPerDegree);
  long logicalB = lround((normalized + 360.0F) * settings.stepsPerDegree);
  return choosePhysicalTarget(logicalToPhysicalSteps(logicalA), logicalToPhysicalSteps(logicalB));
}

bool moveToPhysicalSteps(long target) {
  if (!findingHome && (target < 0 || target > settings.maxSteps)) {
    return false;
  }
  
  // Cancel any pending backlash compensation if new move requested
  backlashCompensating = false;
  
  long current = stepper.currentPosition();
  
  // Backlash compensation: when moving to larger position, overshoot first
  long moveDistance = target - current;
  if (!findingHome && settings.backlashSteps > 0 && moveDistance > 0) {
    long overshoot = target + settings.backlashSteps;
    // Allow overshoot beyond maxSteps by backlashSteps amount for compensation
    long overshootLimit = settings.maxSteps + settings.backlashSteps;
    if (overshoot <= overshootLimit) {
      backlashCompensating = true;
      backlashFinalTarget = target;
      stepper.moveTo(overshoot);
      positionSaved = false;
      return true;
    }
  }
  
  stepper.moveTo(target);
  positionSaved = false;
  return true;
}

bool moveToLogicalSteps(long logicalTarget) {
  long revolutionSteps = 360L * settings.stepsPerDegree;
  long physicalA = logicalToPhysicalSteps(logicalTarget);
  long physicalB = logicalToPhysicalSteps(logicalTarget + revolutionSteps);
  long physicalC = logicalToPhysicalSteps(logicalTarget - revolutionSteps);

  long target = choosePhysicalTarget(physicalA, physicalB);
  target = choosePhysicalTarget(target, physicalC);
  return moveToPhysicalSteps(target);
}

String boolText(bool value) {
  return value ? "true" : "false";
}

String statusResponse() {
  String response = "P ";
  response += physicalToLogicalSteps(stepper.currentPosition());
  response += ";M ";
  response += boolText(stepper.distanceToGo() != 0 || findingHome);
  response += "#";
  return response;
}

String ipToString(const IPAddress &ip) {
  return String(ip[0]) + "." + String(ip[1]) + "." + String(ip[2]) + "." + String(ip[3]);
}

String statusJson() {
  String json = "{";
  json += "\"firmware\":";
  json += FIRMWARE_VERSION;
  json += ",\"positionSteps\":";
  json += physicalToLogicalSteps(stepper.currentPosition());
  json += ",\"targetSteps\":";
  json += physicalToLogicalSteps(stepper.targetPosition());
  json += ",\"mechanicalSteps\":";
  json += stepper.currentPosition();
  json += ",\"targetMechanicalSteps\":";
  json += stepper.targetPosition();
  json += ",\"homeOffsetSteps\":";
  json += settings.homeOffsetSteps;
  json += ",\"zeroPhysicalSteps\":";
  json += zeroPhysicalSteps();
  json += ",\"angle\":";
  json += String(stepsToAngle(stepper.currentPosition()), 2);
  json += ",\"targetAngle\":";
  json += String(stepsToAngle(stepper.targetPosition()), 2);
  json += ",\"isMoving\":";
  json += boolText(stepper.distanceToGo() != 0 || findingHome);
  json += ",\"home\":";
  json += boolText(hallTriggered());
  json += ",\"hold\":";
  json += boolText(settings.hold);
  json += ",\"reversed\":";
  json += boolText(settings.reversed);
  json += ",\"stepsPerDegree\":";
  json += settings.stepsPerDegree;
  json += ",\"maxSteps\":";
  json += settings.maxSteps;
  json += ",\"maxSpeed\":";
  json += settings.maxSpeed;
  json += ",\"acceleration\":";
  json += settings.acceleration;
  json += ",\"manualStep\":";
  json += settings.manualMoveStepSize;
  json += ",\"homeStep\":";
  json += settings.findHomeStepSize;
  json += ",\"apSsid\":\"";
  json += apSsid;
  json += "\",\"apIp\":\"";
  json += ipToString(WiFi.softAPIP());
  json += "\",\"staIp\":\"";
  json += ipToString(WiFi.localIP());
  json += "\",\"staSsid\":\"";
  json += settings.staSsid;
  json += "\",\"tcpPort\":";
  json += ASCOM_TCP_PORT;
  json += ",\"tcpLocked\":";
  json += (strlen(settings.tcpPassword) > 0) ? "true" : "false";
  json += ",\"apCustom\":";
  json += (strcmp(settings.apPassword, "012345678") != 0) ? "true" : "false";
  json += ",\"mdns\":\"";
  json += mdnsHostname;
  json += ".local\"";
  json += ",\"nickname\":\"";
  json += settings.nickname;
  json += "\",\"backlashSteps\":";
  json += settings.backlashSteps;
  json += "}";
  return json;
}

void broadcastStatus() {
  String json = statusJson();
  webSocket.broadcastTXT(json);
}

long commandParameter(String command) {
  if (command.length() <= 1) {
    return 0;
  }
  String param = command.substring(1);
  param.trim();
  return param.toInt();
}
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
void loop() {
  MDNS.update();
  server.handleClient();
  webSocket.loop();
  handleTcpClients();
  handleSerial();
  handleManualButtons();
  serviceHome();
  updateEnablePin();
  stepper.run();

  // Handle backlash compensation: after overshoot, move to final target
  if (backlashCompensating && stepper.distanceToGo() == 0) {
    backlashCompensating = false;
    stepper.moveTo(backlashFinalTarget);
    // Don't save position yet, wait for final move to complete
  }

  if (stepper.distanceToGo() == 0 && !positionSaved && !findingHome && !backlashCompensating) {
    positionSaved = true;
    saveSettings();
    broadcastStatus();
  }

  if (millis() - lastStatusBroadcast > 500) {
    lastStatusBroadcast = millis();
    broadcastStatus();
  }
}

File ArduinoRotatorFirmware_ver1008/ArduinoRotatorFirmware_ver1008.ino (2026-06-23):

#include <AccelStepper.h>

#define DirectionPin  4
#define PulsePin  8
#define EnablePin 5
#define CWPin 6
#define CCWPin 7
#define HEsensorPin 10
#define LEDPin 9

#include <EEPROM.h>

//#include <Bounce.h>
#define DEVICE_RESPONSE "scopfocus Rotator ver 1008"
int ver = 1008;
// EEPROM addresses
#define FOCUSER_POS_START 0
#define STEPPER_SPEED_ADD 3      

AccelStepper stepper(1, PulsePin, DirectionPin);//(mode, step, direction)(1, 11, 7 for old polar ardiuno) 1,13,4 for scope arduino

// Global vars
boolean hold = false;
boolean reversed;
boolean positionSaved;               // Flag indicates if stepper position was saved as new focuser position
boolean firstPrint = false;
boolean homeFound = true;
String inputString;                  // Serial input command string (terminated with \n)
boolean findingHome = false;



// *************  this value must be changed for each specific setup ***************************************
long maxSteps = 72000;  // **** steps needed for 2 complete revolutions.  prevent cord wrap.  
//  Must also enter this value/720 = steps/degree for first time ASCOM driver setup, click "properties 
// ******************************************************************************************************

int manualMoveStepSize = 50;  //higher number for faster manual moves
int findHomeStepSize = 100; //adjusts finding home speed

int buttonStateCW = HIGH;
int buttonStateCCW = HIGH;
boolean manualMoveCW = false;
boolean manualMoveCCW = false;

  int HEState = 0;
  long lastDebounceTime = 0;
//  int counter = 0;
  long debounceDelay = 20;
void loop() 
{

HEState = digitalRead(HEsensorPin);  //goes low by magnet
 
  if (HEState == LOW) {     
    // turn LED on:    
    digitalWrite(LEDPin, HIGH);  
  } 
  else {
    // turn LED off:
    digitalWrite(LEDPin, LOW); 
  }
  
 if (findingHome == true){
   findHome();

 } 
  
  
  
 // Check for CCW manual move 
 buttonStateCCW = digitalRead(CCWPin);
 if (millis() - lastDebounceTime > debounceDelay){ 
 
if (buttonStateCCW == LOW && manualMoveCCW == false){
 
    manualMoveCCW = true;
   //  Serial.println("CCW Debounce ON");
     lastDebounceTime = millis();
  }
  if (buttonStateCCW == HIGH && manualMoveCCW == true){
     

    manualMoveCCW = false;

  lastDebounceTime = millis();
  }
} 

 
 if (manualMoveCCW == true){
  
 //move CW 

stepper.move(-manualMoveStepSize); // change number here to change manual move speed

//manualMoveCW = true;
//Serial.println("CW move");
positionSaved = false;

}

   
  // Check for CCW manual move 
 buttonStateCW = digitalRead(CWPin);
 if (millis() - lastDebounceTime > debounceDelay){ 
 
if (buttonStateCW == LOW && manualMoveCW == false){

    manualMoveCW = true;
 //    Serial.println("CW Debounce ON");
     lastDebounceTime = millis();
  }
  if (buttonStateCW == HIGH && manualMoveCW == true){
    
   manualMoveCW = false;

  lastDebounceTime = millis();
  }
} 

 
 if (manualMoveCW == true){
  
 //move CW 

stepper.move(manualMoveStepSize); // change number here to change manual move speed

//manualMoveCW = true;
//Serial.println("CW move");
positionSaved = false;

}

//if (!manualMoveCW && ! manualMoveCCW){

  // Stepper loop
if (stepper.distanceToGo() == 0){
  if (hold == false){
  digitalWrite(EnablePin, HIGH);
 
}}
  else{
  digitalWrite(EnablePin, LOW);
  }
  if (stepper.distanceToGo() == 0 && !positionSaved){
    saveFocuserPos(stepper.currentPosition());
    positionSaved = true;
  }
   if(stepper.distanceToGo() != 0 && !firstPrint) { 
    firstPrint = true;
     Serial.print("P ");
  Serial.print(stepper.targetPosition());//currentPosition() no accurate until move is done  **** was println, changes w/ adding # below
  Serial.print (";");
  Serial.print("M ");
  Serial.print("true");//true
  Serial.println("#");
//}
}
stepper.run();
}

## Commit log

2026-06-23 Initial ECAA rotator firmware and driver
    [caja_rotador.stl, m54 cover.SLDPRT, m54 cover.STL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]
2026-06-25 fix: CCW pin, Home behavior, UI, and WebSockets compat
    - Change CCW_PIN from D0 to D3 (GPIO16 lacks internal pull-up on ESP8266)
    - Home button now moves to saved zero position instead of Hall sensor homing
    - Manual buttons: edge-triggered instead of level-triggered (prevents floating pin runaway)
    - UI: reduce angle font size, add nowrap, use compact degree symbol
    - Fix WebSockets rvalue-to-lvalue error for library v2.7 compatibility
    [ESP8266RotatorFirmware.ino]
2026-06-29 feat: add ASCOM Sync method + INDI cross-platform driver
    ASCOM Driver:
    - Add Sync(float position) to IRotatorV2 for NINA plate-solving sync
    - Same angle-to-steps formula as existing SetPos on connect
    INDI Driver (new):
    - Support ESP8266 (TCP/Serial) and Arduino Nano (Serial)
    - Cross-platform: Linux/macOS (POSIX termios) + Windows (Win32 CreateFile)
    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
2026-06-29 feat: add Reverse direction support to ASCOM and INDI drivers
    ASCOM:
    - CanReverse now returns true
    - Reverse get/set sends R 0/1# to firmware
    - Reads reversed state from I# JSON on connect
    INDI:
    - Add Reverse switch (custom property, toggles on connected)
    - Sends R 0/1# when toggled
    - Reads reversed state from I# JSON on connect
2026-06-29 feat: add max speed and acceleration control via text protocol
    Firmware:
    - Add A <n># command for acceleration (steps/s²)
    - Add X <n># command for max speed (steps/s)
    - Read-only when no parameter, set when param present
    - MaxSpeed / Acceleration read-write properties
    - Sync on connect via A/X commands
    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
2026-06-29 feat: cap maxSpeed at 3000 steps/s in firmware, ASCOM, INDI
    - X command: clamp val > 3000
    - HTTP /api/settings: clamp maxSpeed > 3000
    - Web UI input: max=3000
    ASCOM: MaxSpeed setter clamps > 3000
    INDI: MAX_SPEED slider range 1..3000
    3000 steps/s = 25°/s at 120 steps/deg — safe for ESP8266 timing
    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
2026-06-29 refactor: dynamic maxSpeed limit = stepsPerDegree × 10
    - X command: clamp to stepsPerDegree * 10 (not hardcoded 3000)
    - HTTP API: same dynamic clamp
    - Web UI: maxAttribute updated from stepsPerDegree in setState()
    ASCOM: MaxSpeed setter clamps to stepsPerDegree * 10
    INDI: MAX_SPEED enforces clamp stepsPerDegree * 10
    Result: 120 steps/° → max 1200 steps/s (10°/s)
    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
2026-06-30 feat: add device nickname, TCP auth, debug logging, and UI improvements
2026-06-30 feat: add backlash compensation, fix coordinate calculation, add NINA plugin
    [ESP8266RotatorFirmware.ino]
2026-06-30 fix: use physical steps for N command to avoid coordinate offset
    - Firmware: N command now accepts physical steps directly instead of logical steps, matching the plugin's calculation formula
    - ASCOM Driver: Add CommandString action to allow NINA plugin to send raw commands (N command for no-backlash moves)
    - NINA Plugin: Use N command for field rotation tracking to avoid triggering backlash compensation; fix version mismatch (1.0->1.2)
    This fixes the issue where field rotation tracking would cause sudden 5 degree jumps due to backlash compensation being triggered incorrectly.
    [ESP8266RotatorFirmware.ino]
2026-06-30 fix: unify Serial/TCP behavior and improve field rotation precision
    - ASCOM Driver: Add StepsPerDegree action for plugin to query
    - ASCOM Driver: Sync stepsPerDegree to firmware on both Serial and TCP (was TCP only)
    - Firmware: N command auto-wraps to nearest valid position within range
    - Plugin: Query stepsPerDegree from driver, preserve sub-step residual for precision
    - Plugin: 10x speed test mode for visible rotation during development
    [ESP8266RotatorFirmware.ino]
